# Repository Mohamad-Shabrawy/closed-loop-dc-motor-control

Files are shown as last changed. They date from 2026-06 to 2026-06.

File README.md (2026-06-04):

# Closed-Loop DC Motor Speed Control (ESP32 + Blynk IoT)

An IoT-enabled closed-loop speed control system for a **775 brushed DC motor** (0–12,000 RPM), built on an **ESP32** microcontroller. Combines a feed-forward duty-cycle model, adaptive bias correction, and a PID controller — controllable both locally and remotely via the **Blynk** cloud platform.

> **Phase 1 Course:** Electro-Mechanical Machines (POW2305) — Helwan National University, Robotics & Mechatronics Dept.  
> **Phase 2 Course:** Electrical Drives (POW2309)  
> **Team:** Youssef Ahmed Rady Elbeltagy · Mohamad Sherif Shabrawy · Amr Sherif Maher *(joined Phase 2)*

---

## Physical Build

| Hardware Top View | Hardware Side View |
|:---:|:---:|
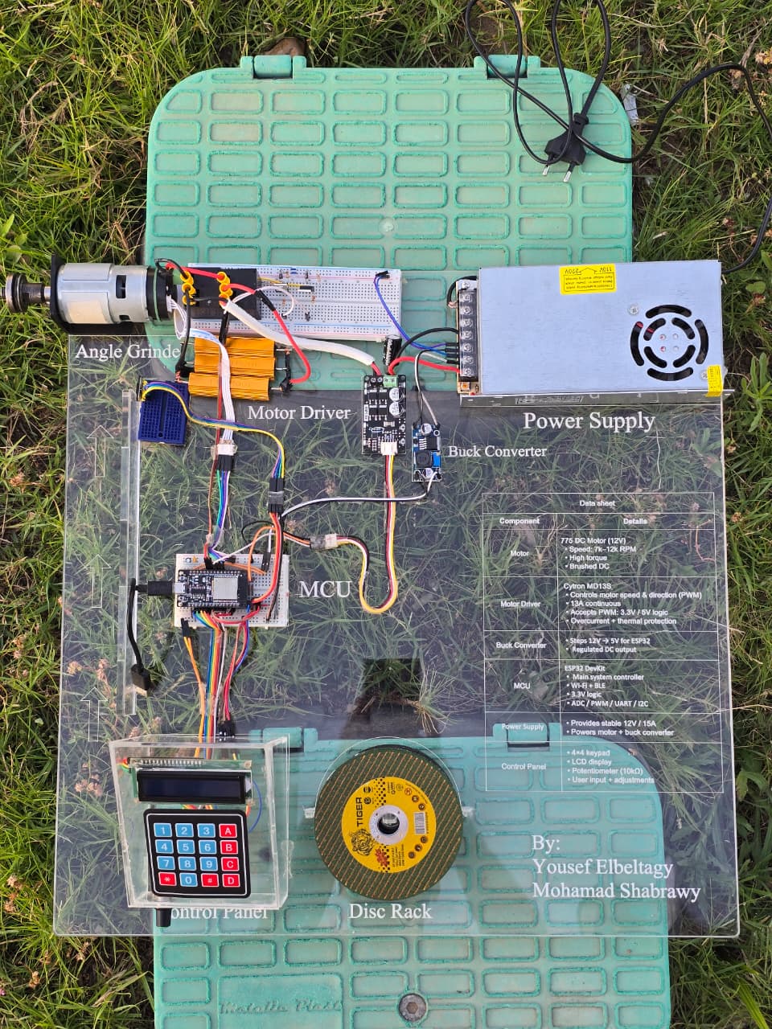
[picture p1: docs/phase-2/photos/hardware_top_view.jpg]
Hardware Top View
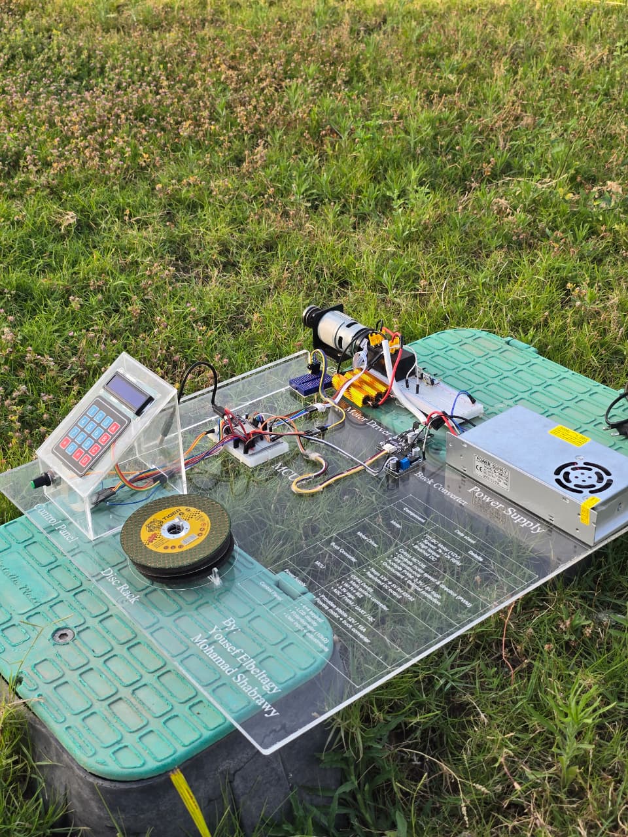
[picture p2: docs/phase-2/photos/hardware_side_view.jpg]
Hardware Side View
|  |  |

| Team Photo | Team Photo |
|:---:|:---:|
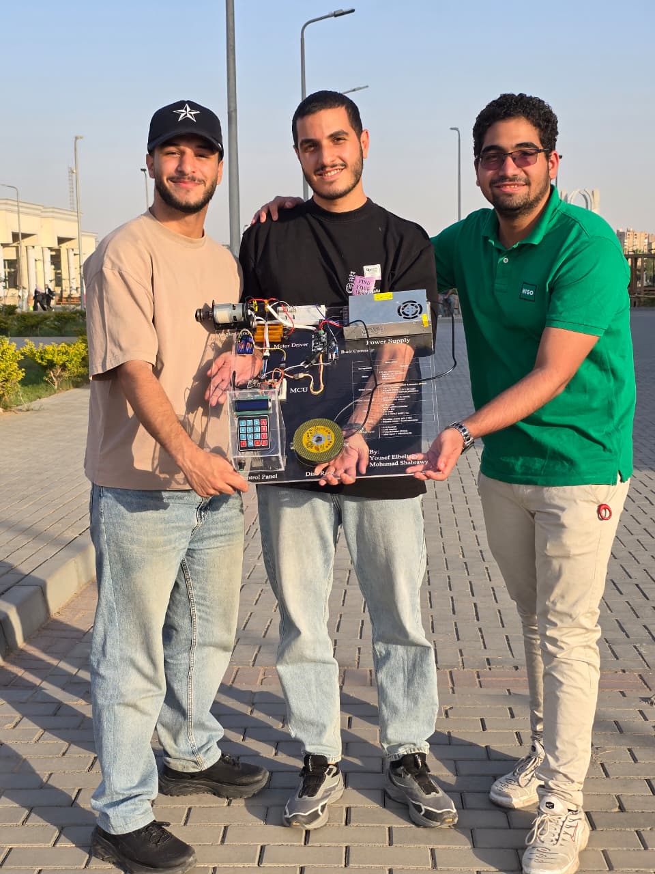
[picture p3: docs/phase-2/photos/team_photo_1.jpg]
Team 1
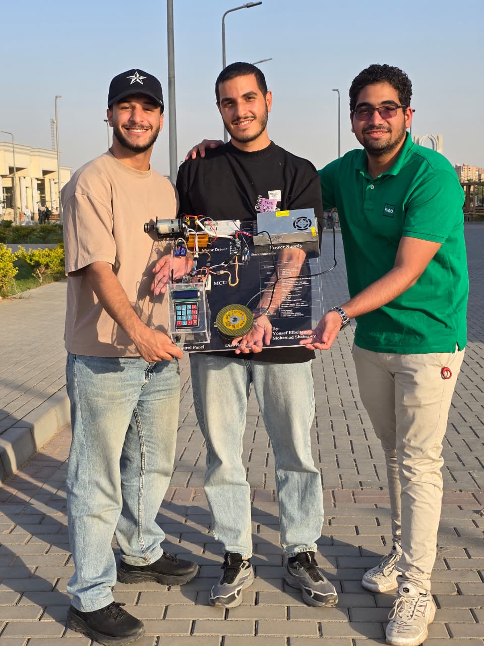
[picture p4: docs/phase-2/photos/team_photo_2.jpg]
Team 2
|  |  |

---

## Project Phases

| | Phase 1 | Phase 2 |
|---|---|---|
| **Focus** | Full working system — firmware, PID control, IoT & physical build | Extended safety features & final presentation |
| **Deliverable** | Complete C firmware + assembled hardware prototype | Dynamic braking circuit, VL6180X sensor, 4×4 keypad upgrade + poster |
| **New in Phase 2** | — | Relay-based dynamic braking, VL6180X obstacle detection, A/B speed ramp keys, C key soft-stop/direction toggle, D key emergency brake |
| **Report** | [Phase 1 Report](docs/phase-1/Closed_Loop_DC_Motor_Report.pdf) | [Phase 2 Poster](docs/phase-2/Project_Poster.pdf) |

---

## System Overview

```
[Keypad / Potentiometer / Blynk App]
              ↓
         ESP32 DevKit
    ┌─────────────────────┐
    │  Feed-Forward Map   │  ← Lookup table (40 RPM→Duty points)
    │  + Adaptive Bias    │  ← Online learning correction
    │  + PID Controller   │  ← Kp=0.02, Ki=0.00015, Kd=0.0006
    └─────────────────────┘
              ↓
      Cytron MD13S Driver
              ↓
       775 DC Motor (12V)
              ↓
    Quadrature Encoder (28 CPR)
              ↑ feedback
```

---

## Features

| Feature | Details |
|---|---|
| Speed range | 0 – 12,000 RPM |
| Control law | Feed-Forward + PID with adaptive bias |
| Speed sensing | Quadrature encoder, 7 PPR × 4 = 28 CPR |
| RPM smoothing | Moving average filter, N=12 circular buffer |
| Input methods | 4×4 keypad, potentiometer, Blynk app |
| IoT platform | Blynk (Wi-Fi via ESP32) |
| Local display | I2C LCD 16×2 + mirrored Blynk LCD widget |
| Safety | Stall detection, overspeed protection, soft start/stop, safe direction change |
| PWM | 20 kHz, 10-bit resolution (GPIO 23 via LEDC) |
| **Dynamic braking** *(Phase 2)* | 2× SPDT relays + 3×1Ω/100W resistors in parallel (0.333Ω, 300W bank) — converts kinetic energy to heat for rapid stop |
| **Emergency obstacle detection** *(Phase 2)* | VL6180X ToF sensor — auto-triggers dynamic braking when object detected within 80 mm (~80–120 ms response) |
| **Speed ramping** *(Phase 2)* | A key = ramp up, B key = ramp down (10 RPM increments) |
| **Configurable soft-stop** *(Phase 2)* | C key (motor stopped) = set deceleration time 1–5 s |
| **Direction toggle** *(Phase 2)* | C key (motor running) = safe stop-then-reverse sequence |
| **Emergency brake key** *(Phase 2)* | D key = instant relay-based dynamic braking |

---

## Hardware

| Component | Spec |
|---|---|
| Microcontroller | ESP32 DevKit |
| Motor | 775 Brushed DC, 12V, 7,000–12,000 RPM |
| Motor Driver | Cytron MD13S (13A continuous) |
| Encoder | Quadrature, 7 PPR |
| Display | I2C LCD 16×2 (address 0x27) |
| Keypad | 4×4 matrix (Phase 2 upgrade from 4×3) |
| Power Supply | 12V, 15A |
| Buck Converter | 12V → 5V for ESP32 |
| **Relays** *(Phase 2)* | SONGLE SLC-12VDC-SL-C SPDT ×2 (12V coil, 30A contacts) |
| **MOSFET drivers** *(Phase 2)* | IRLZ44N ×2 (60V, 50A, logic-level gate) |
| **Braking resistors** *(Phase 2)* | RX24 1Ω/100W ×3 in parallel → 0.333Ω, 300W |
| **Flyback diodes** *(Phase 2)* | 1N4007 ×2 across relay coils |
| **Proximity sensor** *(Phase 2)* | VL6180X ToF via I2C (0–200 mm range) |

**Pin Configuration:**

| Signal | GPIO |
|---|---|
| PWM Output | 23 |
| Direction | 25 |
| Encoder A | 32 |
| Encoder B | 33 |
| Potentiometer | 36 (ADC) |
| Keypad Rows | 19, 18, 5, 17 |
| Keypad Cols | 2, 16, 4, 15 |
| Relay A (Phase 2) | 26 |
| Relay B (Phase 2) | 27 |
| VL6180X SDA (Phase 2) | 21 |
| VL6180X SCL (Phase 2) | 22 |

---

## Blynk Virtual Pin Mapping

| Pin | Role |
|---|---|
| V0 | Live RPM telemetry → graph |
| V1 | Target RPM setpoint (read/write) |
| V2 | Direction (0=Forward, 1=Reverse) |
| V3 | Master Start/Stop switch |
| V4 | Remote LCD widget |

---

## Getting Started

### 1. Install Libraries (Arduino IDE)

- `Blynk` (BlynkSimpleEsp32)
- `LiquidCrystal_I2C`
- `Keypad`

### 2. Configure Credentials

Open `src/Closed_Loop_Motor_Control.c` and fill in your details:

```c
#define BLYNK_TEMPLATE_ID   "YOUR_TEMPLATE_ID"
#define BLYNK_TEMPLATE_NAME "YOUR_TEMPLATE_NAME"
#define BLYNK_AUTH_TOKEN    "YOUR_BLYNK_AUTH_TOKEN"

char ssid[] = "YOUR_WIFI_SSID";
char pass[] = "YOUR_WIFI_PASSWORD";
```

### 3. Flash to ESP32

Open `src/Closed_Loop_Motor_Control.c` in Arduino IDE, select your ESP32 board and COM port, and upload.

### 4. Keypad Controls

| Key | Action |
|---|---|
| `0`–`9` | Type target RPM digit by digit |
| `#` | Confirm → select direction (1=FWD, 2=REV) → start motor |
| `*` | Emergency stop / reset / sync to potentiometer |
| `A` *(Phase 2)* | Hold to ramp speed **up** in 10 RPM increments |
| `B` *(Phase 2)* | Hold to ramp speed **down** in 10 RPM increments |
| `C` *(Phase 2, motor stopped)* | Configure soft-stop deceleration time (1–5 s) |
| `C` *(Phase 2, motor running)* | Toggle direction (safe stop-then-reverse) |
| `D` *(Phase 2)* | Instant **emergency dynamic braking** (relay circuit) |

---

## Control Architecture

### Feed-Forward + Adaptive Bias
A lookup table of ~40 RPM→Duty operating points linearizes the nonlinear motor curve. Linear interpolation finds the base duty for any target RPM. An **online adaptive bias** term updates in real-time when steady-state error persists (10–500 RPM range), compensating for load changes and voltage drop.

### PID Controller
Runs at 150 ms intervals on top of the feed-forward output:

```
u(t) = D_base + Kp·e(t) + Ki·∫e(t)dt + Kd·de(t)/dt
```

- Derivative low-pass filter: α = 0.62
- Integral windup clamp: ±12,000
- Deadband: ±5 RPM (prevents chattering)

### Safety Mechanisms
- **Stall detection:** stops motor if RPM < 20% of target for > 2 s
- **Overspeed protection:** halves duty if RPM > 130% of target for > 1 s
- **Soft start/stop:** ramped duty changes over 30 steps
- **Safe direction change:** direction only changes from full stop

---

## Project Structure

```
closed-loop-dc-motor-control/
├── src/
│   └── Closed_Loop_Motor_Control.c          # ESP32 firmware (C)
├── hardware/
│   └── circuit_layout.dwg                   # AutoCAD electrical layout
├── docs/
│   ├── phase-1/
│   │   └── Closed_Loop_DC_Motor_Report.pdf  # Phase 1 technical report
│   └── phase-2/
│       ├── Project_Poster.pdf               # Phase 2 poster/presentation
│       └── photos/                          # Physical build photos
├── .gitignore
└── README.md
```

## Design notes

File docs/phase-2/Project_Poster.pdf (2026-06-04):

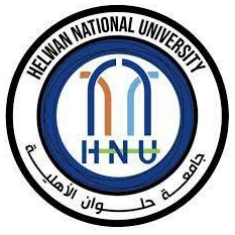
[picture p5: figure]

## HELWAN NATIONAL UNIVERSITY

Faculty of Engineering
Department of Robotics & Mechatronics

## IoT-Enabled Closed-Loop DC Motor Control System with Dynamic Braking

Subject: Electrical Drives

Course Code: POW2309

Student Name: | Student ID:
Yousef Ahmed Elbeltagy | 922230111
Mohamad Sherif Shabrawy | 922230084
Amr Sherif Maher | 922230070

TO: Dr. Eng. Mostafa Rid

Closed-Loop Angle Grinder – IoT-Enabled DC Motor Control

## Table of Contents

Abstract | 3
1. Introduction | 3
2. System Architecture | 3
2.1 Hardware Components | 3
2.2 Software Architecture | 4
2.3 Electrical Interface and Pin Configuration | 7
3. Speed Measurement and Signal Processing | 7
4. Advanced Feed-Forward Control with Adaptive Bias | 8
4.1 Adaptive Bias Correction | 8
5. PID Control Design | 8
5.1 Noise Suppression and Stability | 9
5.2 Integral Windup and Deadband | 9
6. Safety and Protection Mechanisms | 11
7. Dynamic Braking Circuit and Sensor-Based Emergency Protection | 11
7.1 Relay Switching Arrangement | 12
7.2 Braking Resistor Bank | 12
7.3 MOSFET Relay Driver Circuit | 12
7.4 System Wiring Diagram | 13
7.5 VL6180X Sensor Connection and Operation | 13
7.6 Emergency Braking Control Logic | 14
7.7 Dynamic Braking Circuit Component Summary | 14
7.8 Hardware Documentation — Photo Reference 15
8. IoT and Human-Machine Interface (HMI) | 15
8.1 Blynk Virtual Pin Mapping | 15
8.2 Input Arbitrator | 15
9. Experimental Results and Discussion | 15
10. Electrical Drives Concepts Demonstrated | 16
11. Practical Industrial Applications | 17
12. Limitations | 17
13. Conclusion | 17
14. Future Work | 18
15. Appendix | 19

### Design and Implementation of an IoT-Enabled Closed-Loop Speed Control System for a DC Motor Using ESP32

## Abstract

This project presents the design and implementation of an IoT-enabled closed-loop speed control system for a high-speed brushed DC motor using an ESP32 microcontroller. The system integrates encoder-based speed feedback, a feed-forward duty-cycle model, and a PID controller to achieve accurate speed regulation over a wide operating range (0–12,000 RPM). User interaction is supported through a 4×4 matrix keypad with dedicated function keys (A: speed ramp up, B: speed ramp down, C: direction toggle / configurable stop time, D: emergency brake), a potentiometer, a local LCD display, and a cloud-based Blynk interface, enabling both local and remote control.

Safety mechanisms including stall detection, overspeed protection, soft start/stop routines, direction change handling, relay-based dynamic braking, and VL6180X time-of-flight sensor-based automatic emergency obstacle detection are incorporated to ensure reliable and safe operation. The dynamic braking circuit employs two SPDT relays switched by IRLZ44N MOSFET driver circuits to connect the motor across a parallel braking resistor bank (3 × 1Ω, 100W each), converting the motor’s kinetic energy into heat for rapid emergency stopping. Experimental results demonstrate stable speed tracking with near-zero steady-state error under constant load, and robust performance under dynamic setpoint changes.

## 1. Introduction

DC motors are widely used in industrial and embedded applications due to their simplicity, high torque-to-size ratio, and ease of speed control. However, achieving accurate speed regulation over a large operating range requires closed-loop control techniques that compensate for nonlinearities, load variations, and supply fluctuations.

This project focuses on the development of a smart motor control system that combines classical control theory with modern IoT capabilities. The system is designed to:

- Precisely regulate motor speed using encoder feedback
- Allow both local and remote control of speed and direction
- Provide real-time monitoring and safety protection
- Implement relay-based dynamic braking for emergency stopping
- Integrate automatic obstacle detection using a VL6180X time-of-flight sensor
- Demonstrate practical application of PID control and electrical drives concepts in embedded systems

## 2. System Architecture

### 2.1 Hardware Components

The system is composed of the following main hardware components:

- 775 Brushed DC Motor (12V) — Capable of operating between 7,000 and 12,000 RPM with high torque output.
- Cytron MD13S Motor Driver — Provides PWM-based speed control and direction control with up to 13 A continuous current capability. Integrated over-current and thermal protection enhance system safety.
- ESP32 DevKit Microcontroller — Acts as the main controller, providing PWM generation, encoder interfacing, ADC readings, and Wi-Fi connectivity.
- Rotary Encoder — Provides quadrature pulse feedback for real-time speed measurement.
- Buck Converter — Steps down the 12 V supply to a regulated 5 V level for powering the ESP32.
- User Interface Components:
- 4×4 Matrix Keypad for numeric speed entry, direction selection, speed ramping (A/B keys), direction toggle and configurable stop time (C key), and emergency braking (D key)
- Potentiometer for analog speed control
- I2C LCD for local feedback
- Power Supply (12 V, 15 A) — Supplies sufficient current for both motor operation and control electronics.
- SONGLE SLC-12VDC-SL-C SPDT Relay (×2) — 12V coil, 30A contact rating, SPDT configuration used to switch motor terminals between the driver and braking resistor bank.
- IRLZ44N Logic-Level N-Channel MOSFET (×2) — V_DS = 60V, I_D = 50A, R_DS(on) = 0.028Ω. Used as relay coil drivers, directly controlled by ESP32 3.3V GPIO logic.
- RX24-100W Aluminum Case Power Resistor 1Ω (×3) — 100W continuous power rating each. Three in parallel form a 0.333Ω braking bank with 300W combined capacity.
- 1N4007 General Purpose Silicon Diode (×2) — 1A, 1000V. Used as flyback protection across each relay coil.
- TOF050C Module with VL6180X Distance Sensor — Time-of-flight sensor with up to 200 mm detection range, connected via I2C for automatic emergency obstacle detection.

### 2.2 Software Architecture

The firmware is structured into modular subsystems:

- Input handling (keypad, potentiometer, Blynk)
- Speed measurement and filtering
- Feed-forward duty prediction
- PID control loop
- Safety monitoring (stall, overspeed, direction-change guard)
- Dynamic braking and sensor-based emergency protection
- Display and IoT synchronization

A periodic control loop is executed using a timer interrupt at 150 ms intervals.

The flowchart below illustrates the main system loop, showing the non-blocking architecture that handles Wi-Fi synchronization, potentiometer polling, and 4×4 keypad input processing. The keypad branch now includes dedicated paths for numeric speed entry (0–9), direction change (#), A/B speed ramping, C key configurable soft-stop, D key emergency dynamic braking, and * emergency reset.

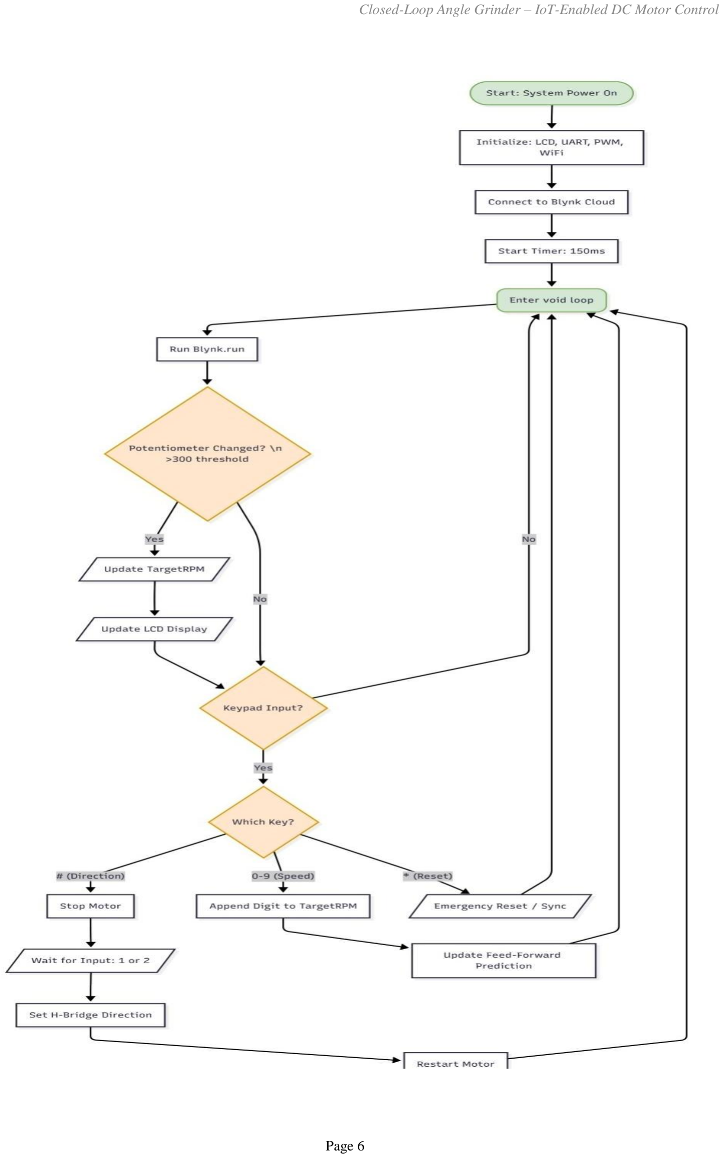
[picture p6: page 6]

Figure 2.1: Main System Loop Flowchart. The non-blocking architecture handles Wi-Fi sync, potentiometer speed control (500 ADC count hysteresis), and 4×4 keypad inputs including speed ramp (A/B), configurable soft-stop (C), emergency dynamic braking (D key — activates relay braking circuit), and emergency reset (*). Direction changes (#) trigger a safe stop-then-reverse sequence.

### 2.3 Electrical Interface and Pin Configuration

To ensure hardware abstraction and modularity, the ESP32 GPIOs were configured with specific electrical characteristics. The system operates on a logic level of 3.3V, interfacing with the 12V motor subsystem via the motor driver.

- PWM Generation: The control signal is generated on GPIO 23 using the ESP32’s
LEDC peripheral. The PWM frequency is set to 20 kHz to minimize audible motor whine, with a resolution of 10 bits (0–1023 duty cycle steps), allowing for fine-grained voltage control.
- Direction Control: Motor direction signal on GPIO 25, connected to the MD13S DIR input. A HIGH output commands forward rotation; LOW commands reverse.
- Quadrature Encoder: The encoder channels A and B are connected to GPIO 32 and GPIO 33 respectively. These pins are configured as INPUT_PULLUP and utilize hardware interrupts to capture state changes on both rising and falling edges, maximizing measurement resolution.
- User Interface:
- Keypad: A 4×4 matrix keypad is mapped to GPIOs 19, 18, 5, 17 (Rows) and 2, 16, 4, 15 (Columns).
- Potentiometer: Analog speed reference is read via GPIO 36 (VP) using the ESP32’s ADC.
- I2C LCD: Driven via standard SDA/SCL lines using the LiquidCrystal_I2C library at address 0x27.
- Relay Driver Outputs: GPIO 26 (Relay A) and GPIO 27 (Relay B) drive the IRLZ44N MOSFET gates. Both pins start LOW at power-on and are driven HIGH together only during an emergency braking event.
- VL6180X Sensor: Connected to ESP32 GPIO 21 (SDA) and GPIO 22 (SCL) via the I2C bus.

## 3. Speed Measurement and Signal Processing

Motor speed is measured using a quadrature encoder with a physical resolution of 7 pulses per revolution (PPR). By counting both rising and falling edges on channels A and B, the effective resolution is quadrupled to 28 counts per revolution (CPR).

The control loop operates at a fixed sampling interval (T_s) of 150 ms. Instantaneous speed is calculated based on the pulse count accumulated over this interval:

(Eq. 1) RPM = (Pulse Count / CPR) × (60 / Δt)
To mitigate quantization noise and measurement jitter, a moving average filter is applied. The firmware utilizes a circular buffer of size N = 12, calculating the smoothed RPM as:

(Eq. 2) RPM_smooth = (1/12) × Σ RPM_raw[i], i = 0, 1, ..., 11
This specific buffer size was selected to balance signal smoothness against phase lag, ensuring the controller remains responsive to rapid setpoint changes.

## 4. Advanced Feed-Forward Control with Adaptive Bias

Due to the nonlinear relationship between PWM duty cycle and motor speed, a feed-forward duty-cycle map was experimentally derived. The map associates discrete RPM values with corresponding PWM duty values.

To linearize the plant model, a lookup table (DutyMap) containing approximately 40 distinct RPM-to-Duty operating points (ranging from 0 to 12,284 RPM) was experimentally derived. The system employs Linear Interpolation to calculate the base duty cycle (D_base) for any requested target speed between calibrated operating points:

(Eq. 3) D_base = D0 + α(D1 − D0)
where α is the interpolation ratio between adjacent speed points.

### 4.1 Adaptive Bias Correction

A novel feature of this implementation is the Adaptive Feed-Forward Bias. Since the static lookup table cannot account for battery voltage drop or varying mechanical loads over time, the system implements an online learning algorithm. When the steady-state error persists between 10 and 500 RPM, the system dynamically adjusts a bias term (dutyBias) for the specific segment of the lookup table:

(Eq. 4) Bias_new = Bias_old + γ × (DutyPerRPM) × Error

Where γ is a learning rate of 0.02. This allows the controller to “learn” the changing system characteristics in real-time, effectively shifting the feed-forward curve to match current operating conditions.

## 5. PID Control Design

To eliminate steady-state errors and improve transient response, a PID controller is implemented on top of the feed-forward term. The control law is given by:

(Eq. 5) u(t) = D_base + K_p·e(t) + K_i·∫e(t)dt + K_d·[de(t)/dt]

where the error signal is defined as:

(Eq. 6) e(t) = RPM_target − RPM_measured
The feedback mechanism utilizes a discrete PID algorithm with the following parameters tuned for the 775 DC motor:

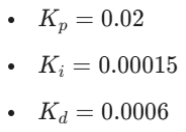
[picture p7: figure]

(Eq. 7) K_p = 0.02, K_i = 0.00015, K_d = 0.0006

### 5.1 Noise Suppression and Stability

To prevent high-frequency noise from amplifying through the derivative term, a Digital Low-Pass Filter (Exponential Moving Average) is applied to the derivative calculation with a smoothing factor of α = 0.62:

(Eq. 8) D_filtered = 0.62·D_prev + (1 − 0.62)·D_raw

### 5.2 Integral Windup and Deadband

To ensure system stability, two additional mechanisms are implemented:

1. Integral Windup Protection: The integral term is strictly constrained between −12,000 and +12,000 to prevent integrator saturation during large error transients.

2. Deadband Zone: A deadband of ±5 RPM is implemented. If the error falls within this range, it is treated as zero, preventing control output oscillation (chattering) around the setpoint.

The flowchart below shows the logic flow of the 150 ms Periodic Interrupt Service Routine (ISR). The ISR first prioritizes safety checks (stall detection and overspeed protection), then checks for VL6180X sensor-triggered emergency braking, before computing the feed-forward lookup, adaptive bias correction, and PID output.

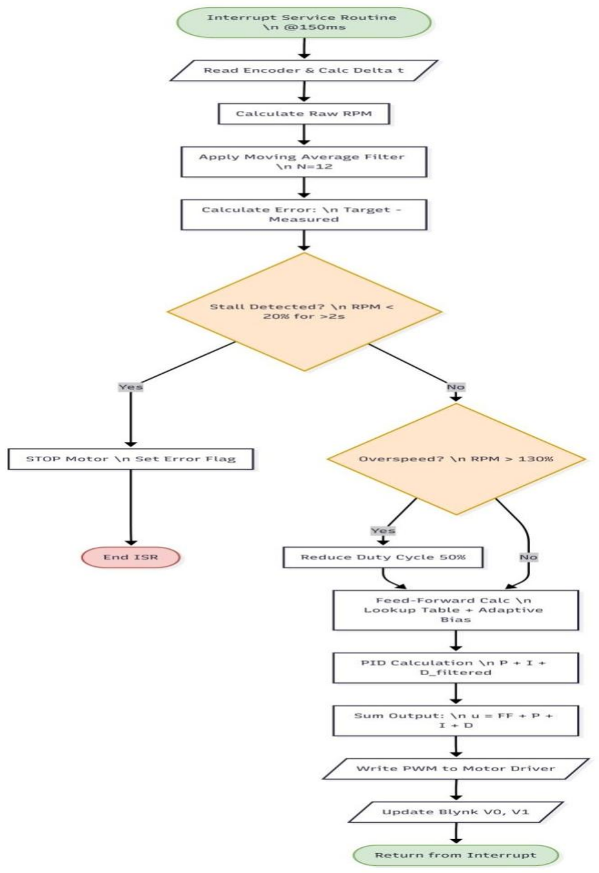
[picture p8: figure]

Figure 5.1: Periodic Interrupt Service Routine (ISR) executing every 150 ms. The routine prioritizes safety checks (stall detection: RPM < 20% of target for >2 s; overspeed: RPM > 130% of target for > 1 s) before executing the adaptive feed-forward lookup table, bias correction, and PID calculation (P + I + D_filtered). The VL6180X sensor emergency braking check is integrated at the safety stage, triggering relay-based dynamic braking when an obstacle is detected within the threshold distance.

## 6. Safety and Protection Mechanisms

Several protection strategies are implemented to ensure safe operation across all conditions:

- Stall Detection: The system monitors if the liveRPM falls below 20% of targetRPM. If this condition persists for 2000 ms (2 seconds) while the target is above 200 RPM, the motor is emergency stopped, and a “STALL ERROR” is triggered on the local display.
- Overspeed Protection: If liveRPM exceeds 130% of targetRPM for more than 1000 ms, the controller automatically halves the duty cycle to protect the mechanical assembly.
- Soft Start / Soft Stop: To reduce inrush current, changes in duty cycle are ramped. The ramp step size is dynamic, calculated as max(ΔDuty / 30, 2), ensuring a smooth transition regardless of the speed jump magnitude.
- Safe Direction Change: Direction changes are only allowed after the motor has been brought to a complete stop, preventing excessive current spikes.
- Relay-Based Dynamic Braking (D Key): Pressing the D key activates two SPDT relays via MOSFET drivers, disconnecting the motor from the driver and connecting it across the braking resistor bank for rapid dynamic braking.
- VL6180X Sensor-Based Automatic Emergency Braking: The time-of-flight sensor continuously monitors for obstacles near the cutting tool at a detection threshold of 80 mm. When an object is detected within this distance for two consecutive readings, the system automatically triggers the same dynamic braking circuit. Sensor detection and braking activation occur within approximately 80–120 ms.
- Configurable Soft-Stop Time (C Key – Motor Stationary): Allows the operator to configure a soft-stop deceleration time between 1 and 5 seconds.
- Live Direction Toggle (C Key – Motor Running): Toggles between forward and reverse with a safe stop-and-restart sequence.
- Hold-to-Ramp Speed Adjustment (A/B Keys): Holding A ramps speed up in 10 RPM increments; holding B ramps it down.

## 7. Dynamic Braking Circuit and Sensor-Based Emergency Protection

The system was upgraded with a relay-based dynamic braking circuit to provide fast stopping of the DC motor during emergency conditions. Two 12V SPDT relays are used together to form a DPDT switching arrangement, with each relay controlling one motor terminal.

### 7.1 Relay Switching Arrangement

In normal operation, the relay common (COM) contacts are connected to the motor terminals, while the normally closed (NC) contacts link the motor to the motor driver. When braking is required, both relays energize simultaneously, moving the motor terminals from NC to normally open (NO) contacts and connecting the motor across the braking resistor bank. The contact wiring is:

- Relay A COM → Motor terminal 1
- Relay B COM → Motor terminal 2
- Relay A NC → Motor driver output terminal 1 (normal run path)
- Relay B NC → Motor driver output terminal 2 (normal run path)
- Relay A NO → One end of the braking resistor bank (braking path)
- Relay B NO → Other end of the braking resistor bank (braking path)

When the relays are de-energized the motor connects normally to the driver. When the relays are energized the motor is isolated from the driver and connected across the resistors.

### 7.2 Braking Resistor Bank

Three RX24-100W aluminum power resistors (1Ω each) are connected in parallel. The equivalent resistance and total power dissipation capacity are:

R_eq = 1 / (1/R₁ + 1/R₂ + 1/R₃) = 1 / (1/1 + 1/1 + 1/1) = 1/3 ≈ 0.333 Ω
(Eq. 9) Equivalent resistance of three 1Ω resistors in parallel
P_total = P₁ + P₂ + P₃ = 100 + 100 + 100 = 300 W
(Eq. 10) Total rated power dissipation of the braking resistor bank
During braking, the rotating DC motor acts as a generator and its kinetic energy is dissipated as heat in the resistor bank. The low equivalent resistance (0.333Ω) maximizes braking current and consequently the braking torque, producing a significantly faster stop than PWM soft-stop alone.

### 7.3 MOSFET Relay Driver Circuit

Each relay coil is driven by an IRLZ44N MOSFET, a logic-level device that can be fully turned on by the ESP32’s 3.3V GPIO output. The wiring for each driver stage is:

- ESP32 relay control GPIO → 100–220Ω gate resistor → IRLZ44N gate
- 10kΩ pull-down resistor from MOSFET gate to GND (prevents false triggering)
- IRLZ44N source → common GND (ESP32 GND and 12V supply negative)

- IRLZ44N drain → relay coil pin 1
- Relay coil pin 2 → +12V supply
- 1N4007 flyback diode across relay coil: cathode → +12V, anode → MOSFET drain

This driver stage is repeated identically for Relay A and Relay B. Both relay control pins are activated together by the ESP32 during any emergency braking event.

### 7.4 System Wiring Diagram

The figure below shows the complete system wiring diagram, illustrating the relay switching paths, MOSFET driver circuits, braking resistor bank, sensor connections, and the normal-run vs. braking power paths.

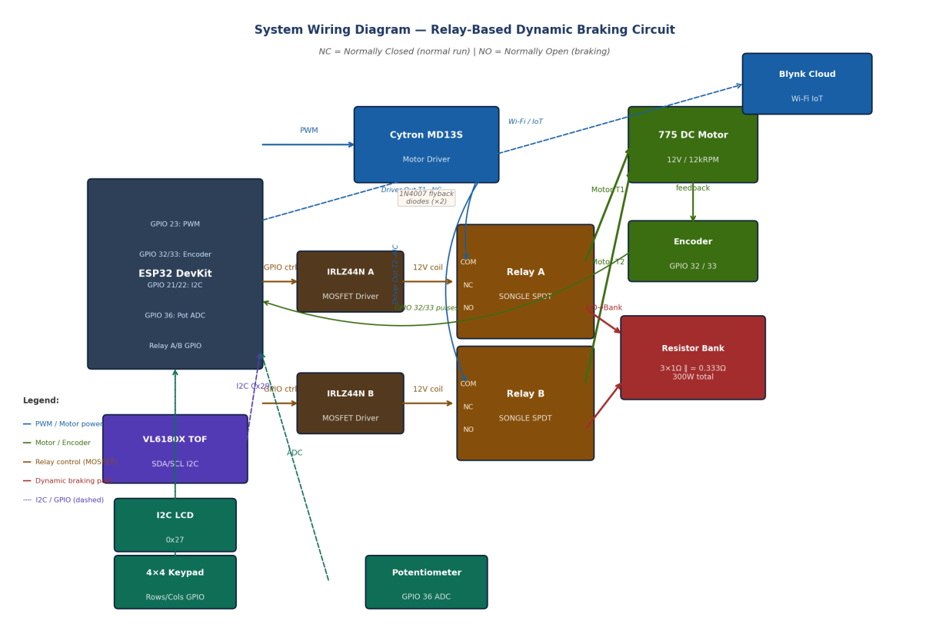
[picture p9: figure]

Figure 7.1: Complete System Wiring Diagram. Blue = PWM/driver paths, Green = motor/encoder, Amber = relay coil control, Red = dynamic braking path, Dashed = I2C/GPIO signals.

### 7.5 VL6180X Sensor Connection and Operation

A VL6180X time-of-flight distance sensor is added as a safety sensor to detect a hand or object near the rotating cutting disc. The sensor is connected to the ESP32 using I2C:

- VL6180X VCC → 3.3V (or 5V depending on module version)
- VL6180X GND → ESP32 GND

- VL6180X SDA → ESP32 GPIO 21
- VL6180X SCL → ESP32 GPIO 22

The sensor is mounted near the cutting tool tip at a fixed height above the workpiece surface. The firmware uses a detection threshold of 80 mm (defined as OBSTACLE_DISTANCE_MM in the code): if the measured distance drops to 80 mm or below for two consecutive readings, the emergency braking routine is triggered. During normal operation the workpiece sits below this threshold. If a finger or hand enters the detection zone, the ESP32 immediately zeros the motor PWM and energizes both relay coils, connecting the motor to the braking resistor bank. Sensor detection and braking activation occur within approximately 80–120 ms, providing a critical safety margin for operator protection.

### 7.6 Emergency Braking Control Logic

The system has two braking trigger methods:

1. Manual emergency braking: Pressing the D key on the 4×4 keypad activates the relay-based dynamic braking circuit.
2. Automatic sensor braking: If the VL6180X detects an object within the threshold distance, the system automatically activates the same circuit.

After either braking event, the operator must press the * (star) key to reset the emergency state and de-energize the relays, returning the system to normal operating mode. This deliberate reset requirement prevents accidental restart after an emergency stop.

### 7.7 Dynamic Braking Circuit Component Summary

# | Component | Qty | Key Specification

1 | SONGLE SLC-12VDC-SL-
| C Relay | 2 | 12V coil, SPDT, 30A contacts
2 | IRLZ44N N-Channel
| MOSFET | 2 | 60V, 50A, R_DS(on) = 0.028Ω
3 | RX24-100W Power Resistor | 3 | 1Ω, 100W, aluminum case
4 | 1N4007 Diode | 2 | 1A, 1000V, flyback protection
5 | TOF050C / VL6180X
| Sensor | 1 | I2C, 0–200 mm range
6 | Gate Resistor | 2 | 100–220Ω, MOSFET gate current
| | | limiting
7 | Pull-Down Resistor | 2 | 10kΩ, MOSFET gate discharge

Figure 7.2: Dynamic Braking Circuit Component Summary Table

## 8. IoT and Human-Machine Interface (HMI)

The system operates a dual-interface architecture allowing synchronized control via physical hardware and the Blynk IoT Cloud.

### 8.1 Blynk Virtual Pin Mapping

- V0: Live RPM Telemetry (Output to Graph)
- V1: Target RPM Setpoint (Input/Output sync)
- V2: Direction Control (0 = Forward, 1 = Reverse)
- V3: Master Start/Stop Switch
- V4: Remote LCD Widget (Mirrors physical LCD)

### 8.2 Input Arbitrator

The firmware acts as an arbitrator between inputs. The physical keypad allows the user to interrupt operation to change direction. The potentiometer input utilizes a 15-sample moving average to filter electrical noise; control authority is granted to the potentiometer only when a change in value exceeds a hysteresis threshold of 500 raw ADC counts, preventing drift from overriding IoT commands.

## 9. Experimental Results and Discussion

Experimental testing was performed to validate system performance across multiple operating scenarios. The following table summarizes key test conditions and observations:

Test Condition | Observation
Normal speed tracking | Stable RPM tracking with very low steady-state error across the full 0–12,000 RPM range
Soft stop (1–5 s) | Motor decelerates smoothly over the operator-selected time; no sudden torque spikes observed
Dynamic braking (D key) | Motor stops significantly faster than soft stop; relay switching and resistor heat dissipation confirmed
Sensor detection | Emergency braking activates automatically when obstacle detected; response time ~80–120 ms
Direction reversal | Motor safely stops before reversing direction; no excessive current spikes observed
A/B hold ramp | Smooth incremental speed control achieved with 10 RPM steps per press
Stall detection | Motor correctly identified stall condition and shut down within 2- second timeout

Overspeed protection | Duty cycle automatically halved when RPM exceeded 130% of target for >1 s

Figure 9.1: Experimental Results Summary

Braking Method Comparison

Soft Stop: The motor decelerates gradually by ramping the PWM duty cycle over the configured 1–5 seconds. This produces minimal mechanical stress but results in a longer stopping distance, which may be unacceptable in safety-critical situations.

Dynamic Braking (D Key): When the operator presses D, the relays switch the motor from the driver to the braking resistor bank. The motor acts as a generator and its kinetic energy is rapidly dissipated as heat. This achieves a significantly faster stop than the soft stop method.

Automatic Emergency Braking (Sensor): The VL6180X sensor triggers the same relay-based dynamic braking circuit automatically. The total response time from sensor detection to relay activation is approximately 80–120 ms under typical operating conditions, providing a meaningful safety margin for operator protection.

The combination of feed-forward control and PID feedback significantly improved response time compared to a pure PID approach. Near-zero steady-state error was consistently observed under constant load conditions, and the system demonstrated robust performance under dynamic setpoint changes.

## 10. Electrical Drives Concepts Demonstrated

This project demonstrates several fundamental electrical drives concepts in a practical embedded system context:

- PWM motor speed control using variable duty-cycle voltage regulation
- Closed-loop feedback control with encoder-based speed measurement
- PID control for steady-state error reduction and transient response improvement
- Dynamic braking through resistive kinetic energy dissipation
- Back-EMF energy recovery and dissipation using a parallel resistor bank during generator-mode operation
- Braking torque generation proportional to motor speed and inversely proportional to braking resistance
- Safe direction reversal with mandatory stop-before-reverse sequencing
- Embedded motor protection including stall detection and overspeed limiting
- Human safety integration using time-of-flight proximity sensing for automatic emergency braking

## 11. Practical Industrial Applications

The system architecture and safety features demonstrated in this project have direct applicability to several industrial and educational domains:

- CNC cutting systems requiring precise speed control and rapid emergency stop capability
- Conveyor belt systems where speed regulation and stall detection are critical
- Automated machine tools with operator proximity safety requirements
- Smart workshop safety systems integrating IoT monitoring with local hardware protection
- Educational motor drive trainers for teaching closed-loop control, PID tuning, and dynamic braking principles

## 12. Limitations

While the system performs well as a prototype, several limitations should be acknowledged for future improvement:

- Relay switching delay: Mechanical relays introduce a finite switching delay (typically 5– 15 ms) compared to solid-state solutions such as MOSFET H-bridges, which switch in microseconds.
- Heat generation in braking resistors: During repeated or prolonged braking events, the aluminum-cased resistors accumulate significant heat. Active cooling may be required for continuous industrial use.
- Sensor calibration dependency: The VL6180X detection threshold must be carefully calibrated for each workpiece height. Changes in workpiece geometry require recalibration.
- Prototype-level safety system: While functional, this is a demonstration-grade implementation. Industrial deployment would require redundant sensors, fail-safe relay configurations, and compliance with relevant machine safety standards.
- Mechanical relay wear: Electromechanical relays have a finite contact life (typically 100,000 operations). High-frequency braking applications would benefit from solid-state relay alternatives.

## 13. Conclusion

This project successfully demonstrates a robust, IoT-enabled DC motor speed control system that integrates classical control theory with modern embedded and cloud technologies. The use of feed-forward modeling, adaptive bias correction, and PID control results in high accuracy, stability, and near-zero steady-state error under normal operating conditions.

The addition of a relay-based dynamic braking circuit, employing two SPDT relays switched by IRLZ44N MOSFET drivers and a parallel braking resistor bank (3 × 1Ω, 300W), enables rapid emergency stopping by converting the motor’s kinetic energy into heat. The integration of a VL6180X time-of-flight sensor provides automatic obstacle detection, triggering the dynamic braking circuit without operator intervention when a hand or foreign object is detected near the cutting tool. Sensor detection and braking activation occur within approximately 80–120 ms.

The upgrade to a 4×4 matrix keypad provides dedicated function keys for speed ramping, direction toggling, configurable soft-stop timing, and one-press emergency braking. The system architecture is scalable and can be extended to higher-power motors, additional sensors, or edge-based AI monitoring in future work.

## 14. Future Work

To elevate this system from a prototype to an industrial-grade solution, the following technical extensions are proposed:

- Model-Based Control & System Identification: Future iterations will implement mathematical modeling to derive the motor’s transfer function parameters (inertia, friction, back-EMF). This enables advanced control strategies like Linear Quadratic Regulation (LQR) or Model Predictive Control (MPC) to optimize performance beyond standard PID limitations.
- Edge-AI Processing on Single Board Computers: Migrating high-level processing to a Raspberry Pi would allow for neural network deployment, enabling features such as real-time PID auto-tuning and intelligent load classification, while the ESP32 remains dedicated to real-time driver actuation.
- Industrial Communication Protocols: To ensure reliability in electrically noisy environments, the current Wi-Fi interface should be supplemented with RS-485 (Modbus) or CAN Bus. These differential signaling protocols provide superior immunity to Electromagnetic Interference (EMI) and allow direct integration with industrial PLCs.
- Predictive Maintenance via Signal Analysis: By integrating current sensors and accelerometers, the system could perform Fast Fourier Transform (FFT) analysis on vibration and current signatures, allowing early detection of mechanical anomalies such as bearing wear or misalignment before catastrophic failure occurs.
- Multi-Sensor Fusion for Enhanced Safety: Future versions could incorporate LiDAR, thermal imaging, or multiple TOF sensors to provide comprehensive operator safety detection beyond the current single-point VL6180X range.
- Regenerative Braking: Implementing regenerative braking to recover kinetic energy into a storage element (supercapacitor or battery) instead of dissipating it as heat would improve energy efficiency, particularly in applications with frequent start-stop cycles.

## 15. Appendix

### 15.1 Firmware Source Code

The complete firmware source code for the ESP32 controller is hosted in a digital repository. This includes the PID algorithm, the feed-forward linearization map, the Blynk IoT integration logic, the dynamic braking relay control, and the VL6180X sensor-based emergency braking system.

Access Instructions: Scan the QR code below using a smartphone camera to view the full C++ source file, or visit the direct link provided.

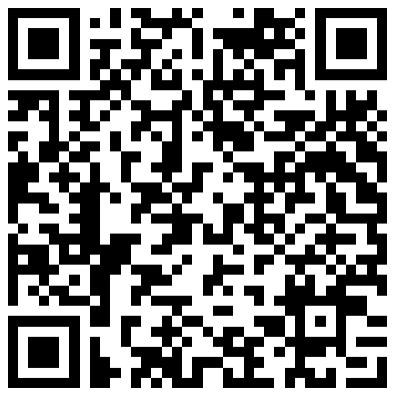
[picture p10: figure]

Figure 15.1: QR Code linking to the Closed_Loop_Motor_Control.cpp source file.

Direct Repository Link:

https://drive.google.com/drive/folders/18FHJYEo4qCkck1h6DbH2Hz4GTF137ZH?usp=drive_link

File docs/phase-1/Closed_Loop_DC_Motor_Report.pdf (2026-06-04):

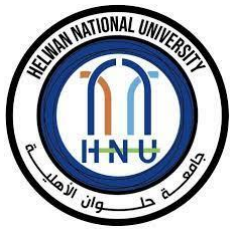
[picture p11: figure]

## HELWAN NATIONAL UNIVERSITY Faculty of Engineering

## Department of Robotics & Mechatronics

Subject: Electro-Mechanical Machines

Course Code: POW2305

Title: Closed loop Angle Grinder

Students Names: | Student ID:
Youssef Ahmed Rady Elbeltagy | 922230111
Mohamad Sherif Shabrawy | 922230084

Submitted TO: Dr. Abdullah Mohamad Teaching Assistant: Ahmad Abdelal

## Design and Implementation of an IoT-Enabled Closed-Loop Speed

# Design and Implementation of an IoT-Enabled Closed-Loop Speed Control System for a DC Motor Using ESP32

## Abstract

This project presents the design and implementation of an IoT-enabled closed-loop speed control system for a high-speed brushed DC motor using an ESP32 microcontroller. The system integrates encoder-based speed feedback, a feed-forward duty-cycle model, and a PID controller to achieve accurate speed regulation over a wide operating range (0–12,000 RPM). User interaction is supported through a keypad, potentiometer, local LCD display, and a cloud-based Blynk interface, enabling both local and remote control. Safety mechanisms including stall detection, overspeed protection, soft start/stop routines, and direction change handling are incorporated to ensure reliable operation. Experimental results demonstrate stable speed tracking, zero steady-state error under load, and robust performance under dynamic setpoint changes.

## 1. Introduction

DC motors are widely used in industrial and embedded applications due to their simplicity, high torque-to-size ratio, and ease of speed control. However, achieving accurate speed regulation over a large operating range requires closed-loop control techniques that compensate for nonlinearities, load variations, and supply fluctuations.

This project focuses on the development of a smart motor control system that combines classical control theory with modern IoT capabilities. The system is designed to:

- Precisely regulate motor speed using encoder feedback
- Allow both local and remote control of speed and direction
- Provide real-time monitoring and safety protection
- Demonstrate practical application of PID control in embedded systems

## 2. System Architecture

### 2.1 Hardware Components

The system is composed of the following main hardware components:

- 775 Brushed DC Motor (12V)
Capable of operating between 7,000 and 12,000 RPM with high torque output.

- Cytron MD13S Motor Driver
Provides PWM-based speed control and direction control with up to 13 A continuous current capability. Integrated over-current and thermal protection enhance system safety.
- ESP32 DevKit Microcontroller
Acts as the main controller, providing PWM generation, encoder interfacing, ADC readings, and Wi-Fi connectivity.
- Rotary Encoder
Provides quadrature pulse feedback for real-time speed measurement.
- Buck Converter
Steps down the 12 V supply to a regulated 5 V level for powering the ESP32.
- User Interface Components
- Keypad for numeric speed entry and direction selection
- Potentiometer for analog speed control
- I2C LCD for local feedback
- Power Supply (12 V, 15 A)
Supplies sufficient current for both motor operation and control electronics.

### 2.2 Software Architecture

The firmware is structured into modular subsystems:

- Input handling (keypad, potentiometer, Blynk)
- Speed measurement and filtering
- Feed-forward duty prediction
- PID control loop
- Safety monitoring
- Display and IoT synchronization

A periodic control loop is executed using a timer interrupt at 150 ms intervals.

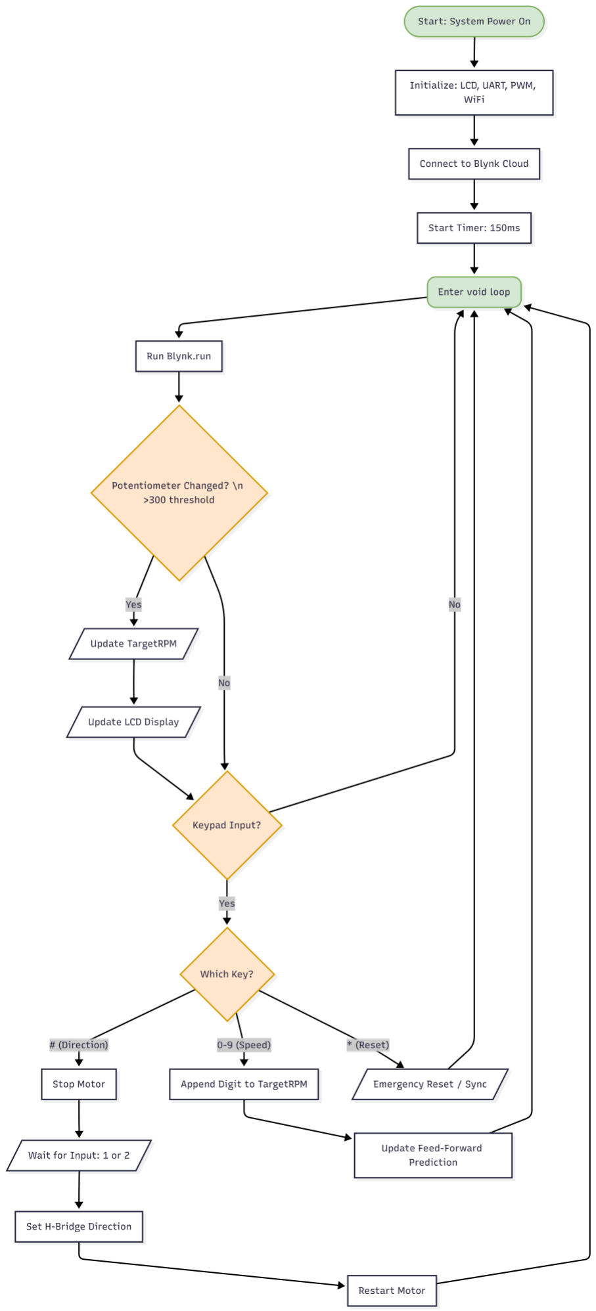
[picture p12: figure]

Figure 2.2: Flowchart of the Main System Loop, illustrating the non-blocking architecture handling WiFi synchronization, user inputs, and mode switching.

### 2.3 Electrical Interface and Pin Configuration

To ensure hardware abstraction and modularity, the ESP32 GPIOs were configured with specific electrical characteristics. The system operates on a logic level of 3.3V, interfacing with the 12V motor subsystem via the motor driver.

- PWM Generation: The control signal is generated on GPIO 23 using the ESP32’s LEDC peripheral. The PWM frequency is set to 20 kHz to minimize audible motor whine, with a resolution of 10 bits (0–1023 duty cycle steps), allowing for fine-grained voltage control.
- Quadrature Encoder: The encoder channels A and B are connected to GPIO 34 and GPIO 35 respectively. These pins are configured as INPUT_PULLUP and utilize hardware interrupts to capture state changes on both rising and falling edges, maximizing measurement resolution.
- User Interface:
- Keypad: A 4x3 matrix keypad is mapped to GPIOs 19, 18, 5, 17 (Rows) and 2, 16, 4 (Columns).
- Potentiometer: Analog speed reference is read via GPIO 36 (VP) using the ESP32’s ADC.
- I2C LCD: Driven via standard SDA/SCL lines using the LiquidCrystal_I2C library at address 0x27.

## 3. Speed Measurement and Signal Processing

Motor speed is measured using a quadrature encoder with a physical resolution of 7 pulses per revolution (PPR). By counting both rising and falling edges on channels A and B, the effective resolution is quadrupled to 28 counts per revolution (CPR).

The control loop operates at a sampling interval (Ts) of 150 ms. Instantaneous speed is calculated based on the pulse count accumulated over this interval.

To mitigate quantization noise and measurement jitter, a moving average filter is applied. The firmware utilizes a circular buffer of size N=12, calculating the smoothed RPM as:

This specific buffer size was selected to balance signal smoothness against phase lag, ensuring the controller remains responsive to rapid setpoint changes.

## 4. Advanced Feed-Forward Control with Adaptive Bias

Due to the nonlinear relationship between PWM duty cycle and motor speed, a feed-forward duty-cycle map was experimentally derived. The map associate's discrete RPM values with corresponding PWM duty values.

To linearize the plant model, a lookup table (DutyMap) containing approximately 40 distinct RPM-to-Duty operating points (ranging from 0 to 12,284 RPM) was experimentally derived. The system employs Linear Interpolation to calculate the base duty cycle (D base) for any requested target speed between these points.

where:

- α is the interpolation ratio between adjacent speed points.

### 4.1 Adaptive Bias Correction

A novel feature of this implementation is the Adaptive Feed-Forward Bias. Since the static lookup table cannot account for battery voltage drop or varying mechanical loads over time, the system implements an online learning algorithm. When the steady-state error persists between 10 and 500 RPM, the system dynamically adjusts a bias term (dutyBias) for the specific segment of the lookup table:

Where gamma is a learning rate of 0.02. This allows the controller to "learn" the changing system characteristics in real-time, effectively shifting the feed-forward curve to match current operating conditions.

## 5. PID Control Design

To eliminate steady-state errors and improve transient response, a PID controller is implemented on top of the feed-forward term.

The control law is given by:

where:

The feedback mechanism utilizes a discrete PID algorithm with the following parameters tuned for the 775 DC motor:

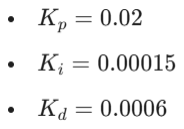
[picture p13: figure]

### 5.1 Noise Suppression and Stability

To prevent high-frequency noise from amplifying through the derivative term, a Digital Low-Pass Filter (Exponential Moving Average) is applied to the derivative calculation with a smoothing factor of alpha = 0.62:

### 5.2 Integral Windup and Deadband

To ensure system stability:

1. Integral Windup Protection: The integral term is strictly constrained between -12,000 and +12,000 to prevent integrator saturation during large error transients.

2. Deadband Zone: A deadband of + or - 5 RPM is implemented. If the error falls within this range, it is treated as zero, preventing control of output oscillation (chattering) around the setpoint.

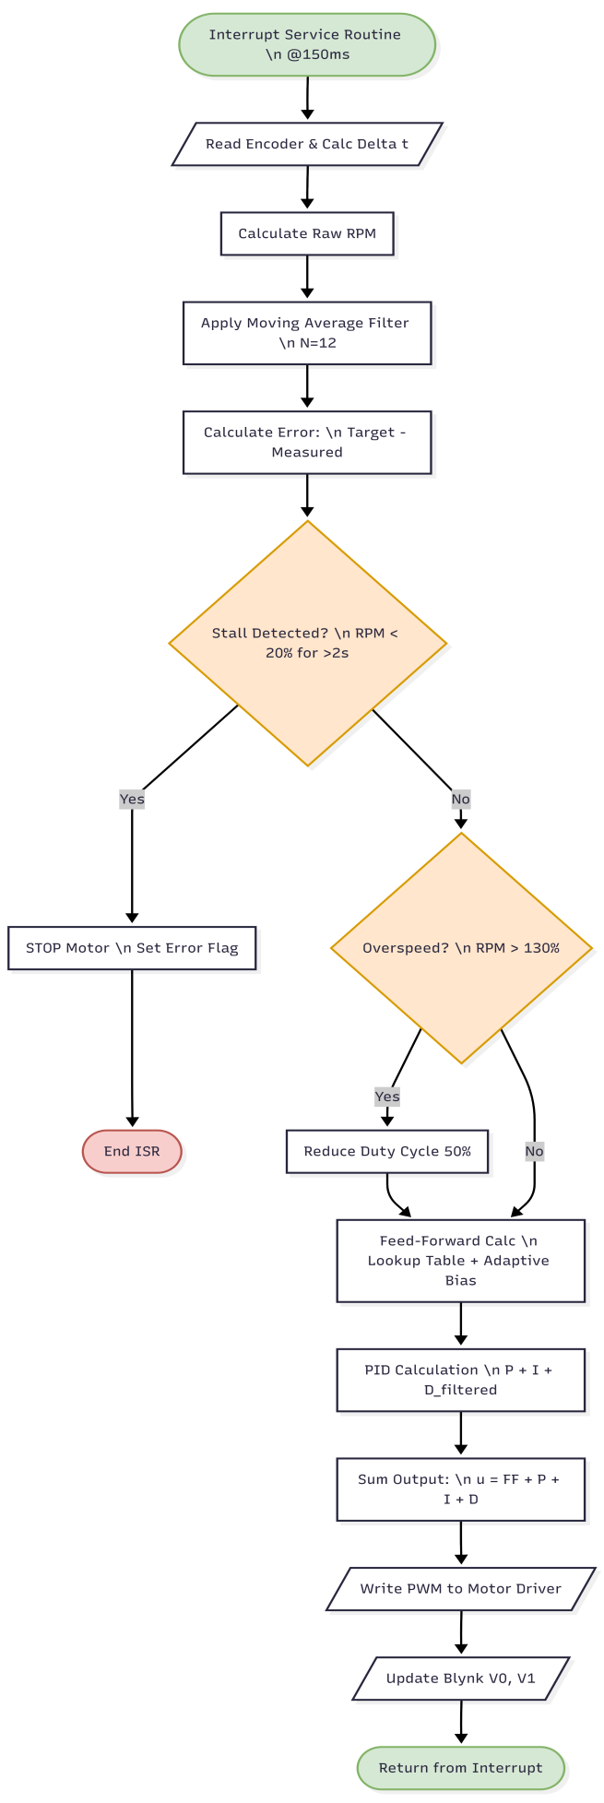
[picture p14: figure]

Figure 5.2: Logic flow of the Periodic Interrupt Service Routine (ISR) executing every 150ms. The routine prioritizes safety checks (Stall/Overspeed) before executing the adaptive Feed-Forward and PID control algorithms.

## 6. Safety and Protection Mechanisms

Several protection strategies are implemented:

- Stall Detection: The system monitors if the liveRPM falls below 20% of targetRPM. If this condition persists for 2000 ms (2 seconds) while the target is above 200 RPM, the motor is emergency stopped, and a "STALL ERROR" is triggered on the local display.
- Overspeed Protection: If liveRPM exceeds 130% of targetRPM for more than 1000 ms, the controller automatically halves the duty cycle to protect the mechanical assembly.
- Soft Start / Soft Stop: To reduce inrush current, changes in duty cycle are ramped. The ramp step size is dynamic, calculated as (Delta Duty / 30, 2), ensuring a smooth transition regardless of the speed jump magnitude.
- Safe Direction Change
Direction changes are only allowed after the motor has been brought to a complete stop.

## 7. IoT and Human-Machine Interface (HMI)

The system operates a dual-interface architecture allowing synchronized control via physical hardware and the Blynk IoT Cloud.

### 7.1 Blynk Virtual Pin Mapping

- V0: Live RPM Telemetry (Output to Graph).
- V1: Target RPM Setpoint (Input/Output sync).
- V2: Direction Control (0 = Forward, 1 = Reverse).
- V3: Master Start/Stop Switch.
- V4: Remote LCD Widget (Mirrors physical LCD).

### 7.2 Input Arbitrator

The firmware acts as an arbitrator between inputs. The physical keypad (# key) allows the user to interrupt operation to change direction. The potentiometer input utilizes a 15-sample moving average to filter electrical noise; control authority is granted to the potentiometer only when a change in value exceeds a hysteresis threshold (300 raw ADC counts), preventing drift from overriding IoT commands.

## 8. Experimental Results and Discussion

Experimental testing demonstrated:

- Accurate tracking of speed setpoints across the full operating range
- Zero steady-state error under constant load conditions
- Stable operation during rapid setpoint changes
- Effective suppression of noise through filtering and feed-forward compensation

The combination of feed-forward control and PID feedback significantly improved response time compared to a pure PID approach.

## 9. Conclusion

This project successfully demonstrates a robust, IoT-enabled DC motor speed control system that integrates classical control theory with modern embedded and cloud technologies. The use of feed-forward modeling, adaptive bias correction, and PID control results in high accuracy, stability, and safety. The system architecture is scalable and can be extended to higher-power motors, additional sensors, or edge-based AI monitoring in future work.

## 10. Future Work

To elevate this system from a prototype to an industrial-grade solution, the following technical extensions are proposed:

- Model-Based Control & System Identification: Future iterations will implement mathematical modeling to derive the motor’s transfer function parameters (inertia, friction, back-EMF). This enables advanced control strategies like Linear Quadratic Regulation (LQR) or Model Predictive Control (MPC) to optimize performance beyond standard PID limitations.
- Edge-AI Processing on Single Board Computers: Migrating high-level processing to a Raspberry Pi would allow for Neural Network deployment. This enables features such as real-time PID auto tuning and intelligent load classification, while the ESP32 remains dedicated to real-time driver actuation.
- Industrial Communication Protocols: To ensure reliability in electrically noisy environments, the current Wi-Fi interface should be supplemented with RS-485 (Modbus) or CAN Bus. These differentials signaling protocols provide superior immunity to Electromagnetic Interference (EMI) and allow direct integration with industrial PLCs.
- Predictive Maintenance via Signal Analysis: By integrating current sensors and accelerometers, the system could perform Fast Fourier Transform (FFT) analysis on vibration and current signatures. This allows for the early detection of mechanical anomalies—such as bearing wear or misalignment—before catastrophic failure occurs.

## 11. Appendix

### 11.1 Firmware Source Code

The complete firmware source code for the ESP32 controller is hosted in a digital repository. This includes the implementation of the PID algorithm, the feed-forward linearization map, and the Blynk IoT integration logic.

Access Instructions: Scan the QR code below using a smartphone camera to view the full C source file, or visit the direct link provided.

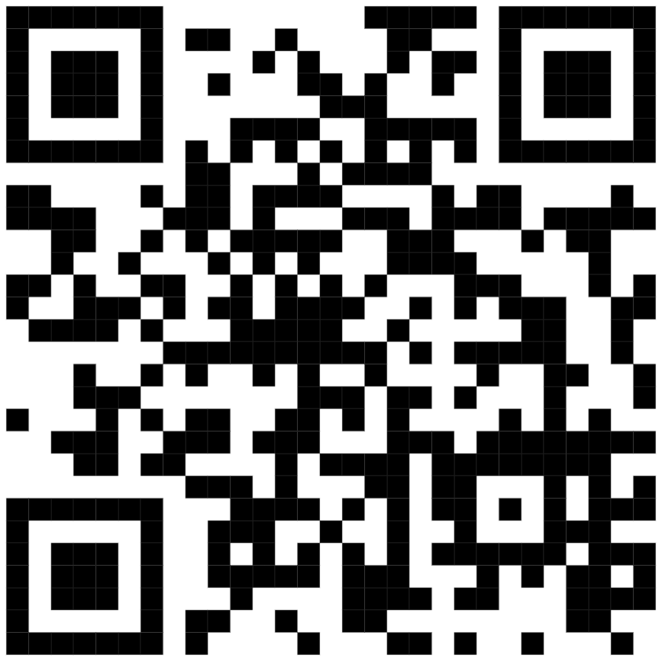
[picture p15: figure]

Figure B.1: QR Code linking to the Closed_Loop_Motor_Control.cpp source file.

Direct Repository Link: [Code is here] (https://drive.google.com/file/d/17lQvymR1_CmdPbl9ZPbcbYsoWcuXuvIt/view?usp=drive_link)

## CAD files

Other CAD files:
hardware/circuit_layout.dwg

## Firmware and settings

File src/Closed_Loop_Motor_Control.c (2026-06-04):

#define BLYNK_TEMPLATE_ID "TMPL2SzwRzWPA"
#define BLYNK_TEMPLATE_NAME "LED ESP32"
#define BLYNK_AUTH_TOKEN "YOUR_BLYNK_AUTH_TOKEN"

#include <WiFi.h>
#include <WiFiClient.h>
#include <BlynkSimpleEsp32.h>
#include <Wire.h>
#include <LiquidCrystal_I2C.h>
#include <Keypad.h>

// -----------------------------------------------------------------------------
// WiFi / Blynk
// -----------------------------------------------------------------------------
char auth[] = BLYNK_AUTH_TOKEN;
char ssid[] = "YOUR_WIFI_SSID";
char pass[] = "YOUR_WIFI_PASSWORD";

BlynkTimer timer;

// -----------------------------------------------------------------------------
// Physical LCD
// -----------------------------------------------------------------------------
LiquidCrystal_I2C lcd(0x27, 16, 2);
void lcdPrintLine(uint8_t row, const String &text) {
  static String last[2] = {"", ""};
  String s = text;
  if (s.length() > 16) s.remove(16);
  while (s.length() < 16) s += ' ';
  if (row > 1 || last[row] == s) return;
  last[row] = s;
  lcd.setCursor(0, row);
  lcd.print(s);
}

// Blynk LCD Widget
WidgetLCD lcdApp(V4);
void showLCD(uint8_t row, String text) {
  lcdPrintLine(row, text);
  if (text.length() > 16) text.remove(16);
  while (text.length() < 16) text += " ";
  lcdApp.print(0, row, text);
}

// -----------------------------------------------------------------------------
// Keypad
// -----------------------------------------------------------------------------
const byte ROWS = 4, COLS = 3;
char keys[ROWS][COLS] = {
  {'1','2','3'},
  {'4','5','6'},
  {'7','8','9'},
  {'*','0','#'}
};
byte rowPins[ROWS] = {19, 18, 5, 17};
byte colPins[COLS] = {2, 16, 4};
Keypad keypad = Keypad(makeKeymap(keys), rowPins, colPins, ROWS, COLS);

// -----------------------------------------------------------------------------
// Motor / Encoder
// -----------------------------------------------------------------------------
#define PWM_PIN    23
#define DIR_PIN    25
#define ENCODER_A  32
#define ENCODER_B  33

volatile long pulseCount = 0;
float liveRPM = 0.0f;
const int PPR = 7;
const int CPR = PPR * 4;

int targetRPM = 0;
bool directionForward = true;
bool motorRunning = false;

const int pwmChannel    = 0;
const int pwmFreq       = 20000;
const int pwmResolution = 10;

int baseDuty = 0;
int currentDuty = 0;

// -----------------------------------------------------------------------------
// Potentiometer
// -----------------------------------------------------------------------------
#define POT_PIN 36
int lastPotRPM = -999;
const int potThreshold = 500; // reduced for faster update

// -----------------------------------------------------------------------------
// Feed-forward curve
// -----------------------------------------------------------------------------
struct DutyMap { int rpm, duty; };

const DutyMap motorCurve[] = {
  {0,0},
  {167,25},
  {505,50},
  {802,75},
  {1111,100},
  {1423,125},
  {1738,150},
  {2053,175},
  {2366,200},
  {2688,225},
  {3010,250},
  {3312,275},
  {3628,300},
  {3936,325},
  {4260,350},
  {4572,375},
  {4877,400},
  {5206,425},
  {5531,450},
  {5846,475},
  {6158,500},
  {6458,525},
  {6778,550},
  {7102,575},
  {7409,600},
  {7733,625},
  {8030,650},
  {8365,675},
  {8684,700},
  {9008,725},
  {9334,750},
  {9625,775},
  {9901,800},
  {10214,825},
  {10523,850},
  {10765,875},
  {11062,900},
  {11347,925},
  {11678,950},
  {11979,975},
  {12000,977},   // derived from your last two points
  {12284,1000}   // measured (above 12k)
};

const int curveSize = sizeof(motorCurve) / sizeof(motorCurve[0]);
float dutyBias[curveSize] = {0};

int predictDuty(int rpmTarget) {
  if (rpmTarget <= 0) return 0;

  if (rpmTarget >= motorCurve[curveSize - 1].rpm) {
    float d = motorCurve[curveSize - 1].duty + dutyBias[curveSize - 1];
    return constrain((int)d, 0, 1023);
  }

  for (int i = 0; i < curveSize - 1; i++) {
    if (rpmTarget >= motorCurve[i].rpm && rpmTarget <= motorCurve[i+1].rpm) {
      float ratio = (float)(rpmTarget - motorCurve[i].rpm) /
                    (motorCurve[i+1].rpm - motorCurve[i].rpm);

      float d0 = motorCurve[i].duty   + dutyBias[i];
      float d1 = motorCurve[i+1].duty + dutyBias[i+1];
      int duty = (int)(d0 + ratio * (d1 - d0));
      return constrain(duty, 0, 1023);
    }
  }
  return constrain(motorCurve[curveSize - 1].duty + dutyBias[curveSize - 1], 0, 1023);
}

void computeBaseDutyFromTargetRPM() {
  baseDuty = predictDuty(targetRPM);
  if (baseDuty > 0 && baseDuty < 60) baseDuty = 60;
}

// -----------------------------------------------------------------------------
// PID
// -----------------------------------------------------------------------------
float Kp = 0.02f;
float Ki = 0.00015f;
float Kd = 0.0006f;
float pidIntegral = 0;
float lastError = 0;
float lastDerivative = 0;
const float DERIVATIVE_FILTER = 0.62f;

float rpmBuf[12] = {0};     // â† CHANGED (20 â†’ 12)
int rpmPtr = 0;

float smoothRPM(float raw) {
  rpmBuf[rpmPtr] = raw;
  rpmPtr = (rpmPtr + 1) % 12;   // â† CHANGED
  float sum = 0;
  for (int i = 0; i < 12; i++) sum += rpmBuf[i];   // â† CHANGED
  liveRPM = sum / 12.0;        // â† CHANGED
  return liveRPM;
}

void IRAM_ATTR readEncoderA() {
  pulseCount += (digitalRead(ENCODER_A) == digitalRead(ENCODER_B) ? 1 : -1);
}
void IRAM_ATTR readEncoderB() {
  pulseCount += (digitalRead(ENCODER_A) != digitalRead(ENCODER_B) ? 1 : -1);
}

void applyDuty(int d) {
  currentDuty = constrain(d, 0, 1023);
  ledcWrite(pwmChannel, currentDuty);
}

void softStartToBaseDuty(int finalBaseDuty) {
  int start = currentDuty;
  int step = max(abs(finalBaseDuty - start) / 30, 2);
  for (int d = start; (finalBaseDuty > start ? d <= finalBaseDuty : d >= finalBaseDuty); d += (finalBaseDuty > start ? step : -step)) {
    applyDuty(d);
    delay(25);
    Blynk.run();
  }
  applyDuty(finalBaseDuty);
}

void softStopToZero() {
  int step = max(currentDuty / 30, 4);
  for (int d = currentDuty; d >= 0; d -= step) {
    applyDuty(d);
    delay(25);
    Blynk.run();
  }
  applyDuty(0);
}

void updateDisplay() {
  static unsigned long last = 0;
  if (millis() - last < 150) return;
  last = millis();

  if (!motorRunning) {
    showLCD(0, "Enter Speed:");
    showLCD(1, String(targetRPM));
  } else {
    showLCD(0, "Set Speed:" + String(targetRPM));
    showLCD(1, "Live Speed:" + String((int)liveRPM));
  }
}

void stopMotor();

void safeSetDirection(bool forward) {
  directionForward = forward;
  digitalWrite(DIR_PIN, forward ? HIGH : LOW);
}

void startMotor() {
  if (targetRPM <= 0) {
    showLCD(0, "Enter Speed:");
    showLCD(1, "");
    return;
  }

  safeSetDirection(directionForward);
  pidIntegral = lastError = lastDerivative = 0;

  for (int i = 0; i < 12; i++) rpmBuf[i] = 0;
  liveRPM = 0;

  computeBaseDutyFromTargetRPM();
  softStartToBaseDuty(baseDuty);
  motorRunning = true;
  updateDisplay();
  Blynk.virtualWrite(V3, 1);
}

void stopMotor() {
  motorRunning = false;
  softStopToZero();
  applyDuty(0);
  showLCD(0, "Motor STOPPED");
  showLCD(1, "");
  delay(500);
  showLCD(0, "Enter Speed:");
  showLCD(1, String(targetRPM));
  Blynk.virtualWrite(V3, 0);
}

// -----------------------------------------------------------------------------
// Potentiometer Fix
// -----------------------------------------------------------------------------
int readPotRPM() {
  long sum = 0;
  const int samples = 15;
  for (int i = 0; i < samples; i++) {
    sum += analogRead(POT_PIN);
    delayMicroseconds(150);
  }
  int avg = sum / samples;
  return map(avg, 0, 4095, 0, 12000);
}

void checkPotControl() {
  int potRPM = readPotRPM();
  if (abs(potRPM - lastPotRPM) > potThreshold) {
    targetRPM = potRPM;
    computeBaseDutyFromTargetRPM();
    Blynk.virtualWrite(V1, targetRPM);
    updateDisplay();      // <--- FIXED
    if (motorRunning) softStartToBaseDuty(baseDuty);
    lastPotRPM = potRPM;
  }
}

// -----------------------------------------------------------------------------
// Blynk handlers
// -----------------------------------------------------------------------------
BLYNK_WRITE(V1) {
  targetRPM = constrain(param.asInt(), 0, 12000);
  computeBaseDutyFromTargetRPM();
  updateDisplay();       // <--- LCD in sync
  if (motorRunning) softStartToBaseDuty(baseDuty);
}

BLYNK_WRITE(V2) {
  bool newForward = (param.asInt() == 0);
  if (newForward == directionForward) return;

  if (motorRunning) {
    stopMotor();
    delay(300);
  }

  safeSetDirection(newForward);
  if (targetRPM > 0 && !motorRunning) {
    computeBaseDutyFromTargetRPM();
    startMotor();
  }
}

BLYNK_WRITE(V3) {
  if (param.asInt() == 1) startMotor();
  else stopMotor();
}

// -----------------------------------------------------------------------------
// updateRPM loop (PID + safety)
// -----------------------------------------------------------------------------
void updateRPM() {
  if (!motorRunning) {
    noInterrupts(); pulseCount = 0; interrupts();
    return;
  }

static unsigned long lastTime = 0;
unsigned long now = millis();

if (lastTime == 0) {          // first call
  lastTime = now;
  return;
}

float dt = (now - lastTime) / 1000.0f;
lastTime = now;

if (dt <= 0.0f) return;       // safety


  noInterrupts();
  long count = pulseCount;
  pulseCount = 0;
  interrupts();

  float rawRPM = (abs(count) / (float)CPR) * (60.0f / dt);
  smoothRPM(rawRPM);

  float error = targetRPM - liveRPM;
  if (abs(error) < 5) error = 0;

  static unsigned long stallStart = 0;
  if (targetRPM > 200) {
    if (liveRPM < targetRPM * 0.2f) {
      if (stallStart == 0) stallStart = now;
      else if (now - stallStart > 2000) {
        stopMotor();
        showLCD(0, "STALL ERROR");
        showLCD(1, "Check load");
        stallStart = 0;
        return;
      }
    } else stallStart = 0;
  }

  static unsigned long overStart = 0;
  if (liveRPM > targetRPM * 1.3f) {
    if (overStart == 0) overStart = now;
    else if (now - overStart > 1000) {
      applyDuty(currentDuty / 2);
      overStart = 0;
    }
  } else overStart = 0;

  if (abs(error) > 10 && abs(error) < 500) {
    int seg = 0;
    for (int i = 0; i < curveSize - 1; i++)
      if (targetRPM >= motorCurve[i].rpm &&
          targetRPM <= motorCurve[i+1].rpm) seg = i;

    float dutyPerRPM = 1023.0f / 12000.0f;
    dutyBias[seg] = constrain(dutyBias[seg] + 0.02f * dutyPerRPM * error, -120.0f, 120.0f);
  }

  for (int i = 0; i < curveSize; i++)
    dutyBias[i] *= 0.9997f;

  baseDuty = predictDuty(targetRPM);

  float derivative = (error - lastError) / dt;
  derivative = DERIVATIVE_FILTER * lastDerivative + (1 - DERIVATIVE_FILTER) * derivative;
  lastDerivative = derivative;
  lastError = error;

  if (abs(error) > 10)
    pidIntegral = constrain(pidIntegral + error * dt, -12000, 12000);

  int duty = baseDuty +
             (int)(Kp * error) +
             (int)(Ki * pidIntegral) +
             (int)(Kd * derivative);

  applyDuty(duty);

  updateDisplay();
  Blynk.virtualWrite(V0, liveRPM);
  Blynk.virtualWrite(V1, targetRPM);
  Blynk.virtualWrite(V2, directionForward ? 0 : 1);
}

// -----------------------------------------------------------------------------
// Setup
// -----------------------------------------------------------------------------
void setup() {
  Serial.begin(115200);
  lcd.init();
  lcd.backlight();

  showLCD(0, "Connecting WiFi");
  showLCD(1, "");

  pinMode(DIR_PIN, OUTPUT);
  digitalWrite(DIR_PIN, HIGH);

  ledcSetup(pwmChannel, pwmFreq, pwmResolution);
  ledcAttachPin(PWM_PIN, pwmChannel);
  applyDuty(0);

  pinMode(ENCODER_A, INPUT_PULLUP);
  pinMode(ENCODER_B, INPUT_PULLUP);
  pinMode(POT_PIN, INPUT);

  attachInterrupt(digitalPinToInterrupt(ENCODER_A), readEncoderA, CHANGE);
  attachInterrupt(digitalPinToInterrupt(ENCODER_B), readEncoderB, CHANGE);

  Blynk.begin(auth, ssid, pass);
  lcdApp.clear();

  timer.setInterval(150L, updateRPM);

  showLCD(0, "Enter Speed:");
  showLCD(1, "0");
}

// -----------------------------------------------------------------------------
// Main loop
// -----------------------------------------------------------------------------
void loop() {
  Blynk.run();
  timer.run();

  static bool newEntry = true;
  static bool typing = false;
  static unsigned long lastKeyTime = 0;


  if (!typing) checkPotControl();

  char key = keypad.getKey();
  if (!key) return;
  lastKeyTime = millis();
  typing = true;
  if (key == '#') {
    typing = false;
    if (motorRunning) {
      stopMotor();
      delay(300);
    }

    newEntry = true;
    showLCD(0, "1:FWD 2:REV");
    showLCD(1, "");

    char dkey = 0;
    while (dkey != '1' && dkey != '2') {
      dkey = keypad.getKey();
      Blynk.run();
      timer.run(); 
    }

    directionForward = (dkey == '1');
    safeSetDirection(directionForward);

    showLCD(0, directionForward ? "FORWARD" : "REVERSE");
    showLCD(1, "");
    delay(600);

    computeBaseDutyFromTargetRPM();
    startMotor();
  }

  else if (key >= '0' && key <= '9') {
    typing = true;
    if (newEntry) {
      targetRPM = 0;
      newEntry = false;
      showLCD(0, "Enter Speed:");
      showLCD(1, "");
    }

    targetRPM = constrain(targetRPM * 10 + (key - '0'), 0, 12000);
    computeBaseDutyFromTargetRPM();
    updateDisplay();
  }

  else if (key == '*') {
    typing = false;
    lastPotRPM = readPotRPM();
    targetRPM = lastPotRPM;
    newEntry = true;
    stopMotor();
  }
}

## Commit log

2026-06-04 Initial commit: Closed-Loop DC Motor Speed Control (ESP32 + Blynk)
    IoT-enabled PID + feed-forward speed controller for a 775 DC motor.
    Features encoder feedback, adaptive bias correction, Blynk cloud
    interface, keypad/potentiometer HMI, and hardware safety protections.
    [circuit_layout.dwg]
2026-06-04 Fix: correct phase descriptions and rename firmware to .c
    - Phase 1 was the complete working project (firmware + hardware), not just design
    - Phase 2 added extended features on top of the working system
    - Renamed Closed_Loop_Motor_Control.cpp → .c (written in C, not C++)
    [Closed_Loop_Motor_Control.c]
2026-06-04 Update README with full Phase 2 features from report
    Phase 2 added:
    - Relay-based dynamic braking (2x SPDT relays + 3x1Ω/100W resistor bank)
    - VL6180X ToF sensor for automatic obstacle emergency braking
    - Upgraded to 4x4 keypad with A/B ramp, C soft-stop/direction, D brake
    - IRLZ44N MOSFET relay drivers with flyback protection
    - Updated pin config, hardware table, and features table
2026-06-04 Fix: correct swapped photo filenames and labels
    Photos were mislabeled — team photos were named as hardware photos
    and vice versa. Renamed and relabeled correctly:
    - hardware_top_view.jpg → actual labeled top-down circuit photo
    - hardware_side_view.jpg → actual side-angle hardware photo
    - team_photo_1/2.jpg → actual team photos with project
2026-06-04 Restore README and fix photo labels correctly
    README was corrupted during disk-full crash. Restored from git history
    and correctly applied photo label fix:
    - hardware_top_view.jpg = labeled top-down circuit board photo
    - hardware_side_view.jpg = side-angle hardware photo
    - team_photo_1/2.jpg = team holding the project
